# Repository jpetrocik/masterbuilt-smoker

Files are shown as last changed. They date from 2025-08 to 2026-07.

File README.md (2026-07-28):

# Smart Smoker Controller System

This project replaces the standard control board in an electric smoker, adding Wi-Fi, PID heat control, four built-in meat probes, a companion mobile app, and more. I can remotely monitor and control the cook from anywhere without being tied down to the smoker. The custom PID algorithm maintains an almost perfect internal temperature with minimal fluctuations. A variety of push notifications eliminate the need to constantly check on the cook throughout the day and night.

The primary goal of this project is to give me my weekend back. I don't want to constantly babysit the smoker when I rather be spending the day snowboarding, hitting trails, off-roading, or just hanging out with friends. The controller continuously monitors the smoker and meat temperature, sending real-time notifications to my phone when probes hit their target temperatures.

This specific board was designed as a drop-in replacement for Masterbuilt refrigerator-style smokers, but the system can be adapted to work with almost any electric smoker.

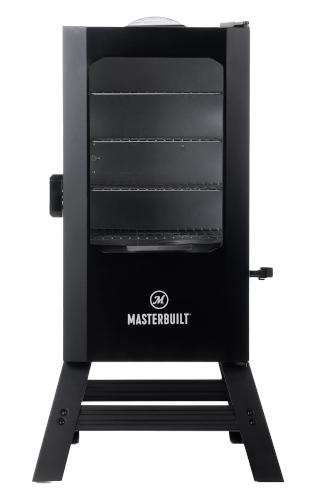
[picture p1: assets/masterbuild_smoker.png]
Masterbuilt Smoker


## Overview

This repository is split into four major components, each with its own detailed `README.md` file:

### 1. Mobile App (./www/README.md)
A Progressive Web App (PWA) that can be installed on your phone to run exactly like a native app, complete with real-time push notifications.

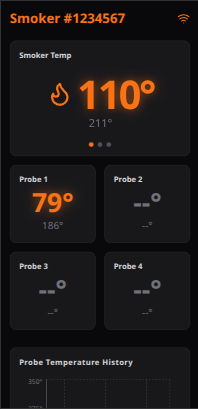
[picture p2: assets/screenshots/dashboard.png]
Dashboard Screenshot


### 2. Backend (./server/README.md)
The central nervous system of the project. It acts as the bridge between the physical smoker and the mobile application. The backend handles the complex algorithms for stall detection and logs high-resolution temperature history. The system is highly fault-tolerant: if the backend drops offline, the firmware will continue executing the active cook locally. If the backend loses connection to the smoker, an alert is sent immediately to your phone.

### 3. Firmware (./firmware/README.md)
The embedded code running on the physical microcontroller (ESP32) that directly interfaces with the smoker's hardware.

### 4. Hardware & PCBs (./hardware/README.md)
This directory contains the custom board designs. Currently, there are two boards designed to support Masterbuilt smokers: the main controller PCB and the power module. The custom power module replaces the stock mechanical relay with a Solid State Relay (SSR) to easily tolerate the rapid on/off switching required by the PID heat control.

## 📂 Repository Structure

```text
├── /server             # Node.js backend
├── /firmware           # Microcontroller code (ESP32/Arduino)
├── /www                # React / Vite / Tailwind PWA
├── /hardware           # Schematics and Gerber files
└── README.md           # Project overview (You are here)

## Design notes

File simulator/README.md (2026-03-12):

# Smoker Simulator

A Node.js-based MQTT simulator for testing the smoker backend and frontend.

## Features

- Simulates smoker temperature and probe temperatures using a realistic random walk algorithm
- Implements MQTT presence with Birth and Last Will and Testament (LWT) messages
- Publishes telemetry data to `smoker/<smokerId>/status` every 5 seconds
- Subscribes to and handles commands on `smoker/<smokerId>/command`
- Configurable number of active probes (0-4)

## Installation

1. Install dependencies:
```bash
npm install
```

## Configuration

Edit `config.json` to customize the simulator:

```json
{
  "smokerId": "smoker123",
  "mqttBroker": "mqtt://localhost:1883",
  "publishInterval": 5000,
  "activeProbes": 4
}
```

- **smokerId**: Unique identifier for the smoker
- **mqttBroker**: MQTT broker URL
- **publishInterval**: Telemetry publish interval in milliseconds
- **activeProbes**: Number of probes (0-4) that are "plugged in"

## Running the Simulator

```bash
npm start
```

The simulator will:
1. Connect to the MQTT broker
2. Publish an "online" birth message to `smoker/<smokerId>/presence`
3. Subscribe to `smoker/<smokerId>/command`
4. Publish telemetry data every 5 seconds to `smoker/<smokerId>/status`

## Telemetry Payload Structure

The simulator publishes JSON payloads matching the firmware structure:

```json
{
  "temperature": 224.5,
  "targetTemperature": 225.0,
  "cookTimer": 240,
  "cookTime": 300,
  "dutyCycle": 0.75,
  "probe1": 145.2,
  "targetProbe1": 165,
  "alarmProbe1": false,
  "probe2": 151.3,
  "targetProbe2": 160,
  "alarmProbe2": false
}
```

## Supported Commands

The simulator listens for and handles the following commands on `smoker/<smokerId>/command`:

- `setCookTime=<minutes>` - Set cook timer countdown
- `setProbeXTarget=<temp>` - Set probe X target temperature (X=1-4)
- `setProbeXLabel=<label>` - Set probe X label (logged but not stored)

## Random Walk Algorithm

Temperatures don't jump randomly but follow a realistic trend:
- Start at 75°F
- Each interval, add a random value between -1.0 and +2.0
- Cap maximum temperature at 225°F
- This creates a natural heating trend for frontend chart testing

## MQTT Topics

| Topic | Direction | Description |
|---|---|---|
| `smoker/<smokerId>/presence` | Publish | LWT/Birth messages ("online"/"offline") |
| `smoker/<smokerId>/status` | Publish | Telemetry data (JSON) |
| `smoker/<smokerId>/command` | Subscribe | Commands from backend/frontend |

## Testing with Backend

1. Start your backend server
2. Start the simulator: `npm start`
3. The backend should detect the smoker as "online" via the presence topic
4. Telemetry data will be published every 5 seconds

## Testing with Frontend

1. Start the backend server
2. Start the simulator
3. Start the frontend (from the `www` directory)
4. The frontend should display real-time smoker and probe data

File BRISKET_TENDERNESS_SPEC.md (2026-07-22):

# Brisket "Percent Done" / Tenderness Calculation Service

## Overview

Brisket tenderness is achieved through rendering collagen into gelatin. This rendering process is non-linear and accelerates exponentially at higher internal temperatures. This service calculates cumulative collagen rendering as a percentage (0-100%+) based on historical probe1 temperature telemetry from the smoker.

## Context

- Brisket cooks can run 12-18+ hours
- The smoker records probe telemetry every ~5 seconds, yielding massive datasets
- A direct calculation on raw 5-second data is expensive; aggregation to 1-minute intervals is more practical
- The calculation is slow enough that running it on every telemetry update (5-second intervals) is wasteful
- The metric is inherently slow-moving and doesn't require real-time precision

## Rendering Rate Model

The "Rendering Rate" (percentage of collagen rendered per hour) is determined by internal probe temperature, mapped via a lookup table. These rates represent the collagen-rendering speed at each temperature band.

| Temperature Range | Rate (% per hour) |
|---|---|
| < 140°F | 0% |
| 140–149°F | 1% |
| 150–159°F | 2% |
| 160–169°F | 3% |
| 170–179°F | 5% |
| 180–189°F | 9% |
| 190–194°F | 18% |
| 195–199°F | 25% |
| 200–204°F | 35% |
| 205–209°F | 55% |
| ≥ 210°F | 75% |

## Design Decisions

### 1. Where to Store the Calculated Value
- **Choice**: Include `percentRendered?: number` as an optional field in `SmokerTelemetryData`
- **Why**: The field is transient, computed, and specific to the WebSocket consumer. It doesn't belong in the persistent database record.
- **Implementation**: `insertTelemetry()` uses explicit column bindings, so adding the field to the interface has no DB side effects.

### 2. Calculation Frequency
- **Choice**: Run every 5 minutes via `setInterval`
- **Why**: Avoids expensive DB aggregation on every 5-second telemetry pulse. 5-minute staleness is acceptable for a slow-moving cook metric.
- **Alternative considered**: Lazy calculation with per-smoker 5-minute debounce (would add complexity; interval-based is simpler).

### 3. Active Smoker Tracking
- **Choice**: Track smokers via a `Set<string>` that gets populated on every telemetry event and cleared after each calculation tick
- **Why**: The scheduler doesn't need to query the database to find "active" smokers; they're implicitly the ones sending telemetry.
- **Scalability**: If there are many offline smokers, this avoids unnecessary calculations.

### 4. Cook Start Time
- **Choice**: Use `MIN(timestamp)` from `cook_history` for the smoker
- **Why**: Simple, authoritative, and doesn't require external tracking or configuration.
- **Limitation**: If history retention (`maxHistoryHours`) is shorter than the cook duration, the true cook start is lost. The calculation will be undercount. (Future enhancement: allow explicit cook start time tracking.)

### 5. Injection Point
- **Choice**: Attach `percentRendered` in `mqttService.ts:handleStatusMessage` before emitting to `telemetryEmitter`
- **Why**: Centralizes the enrichment logic at the source, and the WebSocket server receives already-augmented data.
- **Consideration**: The raw telemetry stored in `cook_history` never has `percentRendered` — it's a computed, transient field.

## Implementation

### Type Changes
**`server/src/types/index.ts`**
- Add `percentRendered?: number` to `SmokerTelemetryData` interface

### Database Functions
**`server/src/database/database.ts`**

Two new functions:

```typescript
export function getCookStartTime(smokerId: string): number | null
```
Returns the minimum timestamp from `cook_history` for the given `smokerId`, or `null` if no records exist.

```typescript
export function getMinuteAveragedProbeData(
  smokerId: string,
  startTime: number,
  endTime: number
): Array<{ minuteBucket: number; avgProbe1Temperature: number }>
```
Aggregates telemetry into 1-minute buckets and returns average probe1Temperature per bucket. Uses `timestamp / 60000` for bucketing (integer division in SQLite). Filters for `probe1Temperature IS NOT NULL`.

### Brisket Service
**`server/src/brisket/brisketService.ts`** (NEW file)

Exports:
- `startBrisketScheduler()` — initializes the 5-minute interval. Called once at server startup.
- `markSmokerActive(smokerId: string)` — records that a smoker has sent telemetry. Called on every MQTT status message.
- `getCachedPercentRendered(smokerId: string)` — returns the cached value (may be `undefined` if not yet computed). Called before emitting telemetry.

Internals:
- In-memory `Map<string, number>` for the cache (keyed by smokerId)
- In-memory `Set<string>` for active smokers
- `getRenderingRate(tempF: number): number` — switch/if-chain lookup
- `computeAndCache(smokerId: string)` — executes the full calculation pipeline

### MQTT Service Integration
**`server/src/mqtt/mqttService.ts`**

Two small changes:

1. In `connectMqtt()`, call `startBrisketScheduler()` alongside the existing `purgeOldHistory` interval.
2. In `handleStatusMessage()`, before emitting:
   - Call `markSmokerActive(smokerId)`
   - Retrieve `getCachedPercentRendered(smokerId)`
   - If defined, attach it to the outbound telemetry object before emitting

---

## Data Flow

```
Smoker sends MQTT status (every ~5 seconds)
  ↓
MQTT topic parsed → smokerId extracted
  ↓
handleStatusMessage(smokerId, payload)
  ├─ markSmokerActive(smokerId)
  ├─ insertTelemetry(timestampedData)                    [raw data, no percentRendered]
  ├─ percentRendered = getCachedPercentRendered(smokerId) [may be undefined]
  └─ telemetryEmitter.emit('telemetry', { ...data, percentRendered? })
       ↓
       WebSocket server broadcasts { type: 'live', data: enrichedTelemetry }
       ↓
       Frontend receives percentRendered (if defined)

Every 5 minutes (setInterval)
  ↓
brisketScheduler tick
  ├─ for each smokerId in activeSmokers:
  │   ├─ startTime = getCookStartTime(smokerId)
  │   ├─ buckets = getMinuteAveragedProbeData(smokerId, startTime, now)
  │   ├─ total = Σ(getRenderingRate(bucket.temp) / 60)
  │   └─ cache.set(smokerId, round(total, 2 decimals))
  └─ activeSmokers.clear()
```

---

## Edge Cases & Mitigations

### 1. First 5 Minutes of Uptime
- **Case**: Server starts but scheduler hasn't fired yet; telemetry arrives with `percentRendered: undefined`
- **Mitigation**: Frontend should handle missing field gracefully (display "—" or omit from UI)
- **Is this acceptable?** Yes for this project. If strict: could pre-compute for all smokers on startup.

### 2. Probe Unplugged / No Temperature Data
- **Case**: All `probe1Temperature` values are NULL for a smoker
- **Database query**: `getMinuteAveragedProbeData` returns empty array
- **Result**: `percentRendered` caches as `0.00`
- **Is this acceptable?** Yes. A missing probe means no rendering data available; zero is sensible.

### 3. Cook Longer Than History Retention Window
- **Case**: Cook runs 18 hours, but `maxHistoryHours` is 12
- **Impact**: `getCookStartTime` returns the oldest retained record, not the true cook start
- **Result**: Rendering percentage is underestimated
- **Mitigation**: Document the limitation. Future enhancement: track explicit cook start time in a separate table or in-memory map.

### 4. Multiple Concurrent Calculations for Same Smoker
- **Case**: If manual refresh or ad-hoc endpoint also triggers calculation
- **Impact**: Race condition on cache write (minor; last-write wins)
- **Mitigation**: Current design is simple and acceptable for single-server deployment. For HA, consider a lock or atomic update.

### 5. Stale Cache Across Server Restarts
- **Case**: Server restarts; cache is in-memory and lost
- **Impact**: First telemetry after restart has `percentRendered: undefined` until next 5-min tick
- **Mitigation**: On startup, could populate cache by running calculation for all smokers in DB. Not done currently to keep startup fast.

### 6. Smoker Inactive for > 5 Minutes
- **Case**: Telemetry stops arriving; `activeSmokers` set becomes empty
- **Impact**: Calculation no longer runs; cached value freezes at last update
- **Is this acceptable?** Yes. A frozen value for an inactive cook is correct. When telemetry resumes, the next tick will update it.

---

## Performance Considerations

- **Database query**: Compound index on `(smokerId, timestamp)` ensures the aggregation query is efficient even over 18 hours of data (≈65k 5-sec records = 1080 1-min buckets per cook).
- **Calculation cost**: One aggregation query + 1080 loop iterations (max) every 5 minutes. Negligible on a single-smoker or low-smoker workload.
- **Memory**: Cache is `Map<string, number>` (~64 bytes per smoker per entry). For 100 smokers, ~6.4 KB. Negligible.

---

## Testing / Verification

### Unit / Integration Test Ideas
1. Mock a sequence of temperature readings in different rate bands, verify the aggregation and sum.
2. Test `getRenderingRate()` edge cases (139.9°F, 140.0°F, 209.9°F, 210.0°F).
3. Test empty probe data returns 0%.

### Manual Verification
1. Start server + simulator; let it run 5+ minutes.
2. Open WebSocket connection; observe incoming `live` messages.
3. After first scheduler tick, `percentRendered` should appear in the data.
4. Manually run the aggregation SQL on the SQLite DB; compute a few buckets by hand.
5. Verify the cached value matches the manual calculation.

### Acceptance Criteria
- [ ] `percentRendered` appears in WebSocket `live` messages after first 5-min tick
- [ ] Value is a float rounded to 2 decimal places
- [ ] Value increases monotonically (or stays flat if probe temp doesn't rise)
- [ ] Value matches manual calculation from database

---

## Future Enhancements

1. **Explicit Cook Start Tracking**: Store cook start time in a separate table or in `smokers` table. Allow frontend to reset the clock mid-cook.
2. **Different Probes**: Generalize from `probe1` to any probe (most cooks use probe1, but some may use probe2 for brisket).
3. **Pre-Computed History**: Store daily snapshots of `percentRendered` for completed cooks (analytics / archive).
4. **Confidence Intervals**: If gaps exist in telemetry, note that the calculation is based on partial data.
5. **Temperature-Specific Alerts**: "Rendering accelerating — collagen breakdown in progress" at 190°F+.
6. **Target Rendering Level**: Allow user to set a target (e.g., 85%) and alert when reached, rather than just displaying a number.

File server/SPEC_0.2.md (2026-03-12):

## 1. Iteration 2: Hardware Control & Command Forwarding

### 1.1 Objective
Enable two-way communication by allowing connected WebSocket clients to send configuration and control commands down to the physical smoker hardware. The Node.js backend will act as a validating bridge, translating JSON WebSocket messages into plain-text MQTT payloads.

### 1.2 MQTT Command Contract
The backend will publish commands to a dedicated topic for each tenant.
* **Command Topic:** `smoker/<smoker_id>/command`
* **Payload Format:** Plain text string in `key=value` format (or just `key` for flag commands).
* **QoS:** `1` (At least once delivery ensures commands are not lost).
* **Retain:** `false` (Commands are instantaneous actions, not persistent states).

### 1.3 WebSocket Client-to-Server Protocol
Clients with an active WebSocket connection to `/smoker/<smoker_id>/data` can push messages to the server. The server must listen for incoming `message` events on the socket.
* **Expected Client Payload:** JSON object containing the command key and an optional value.
  ```json
  {
    "action": "command",
    "commandKey": "setTemp",
    "commandValue": 225
  }```

### 1.4 Protocol
* setTemp=[temp]
Set the target temperature (°F or °C, depending on configuration smoker configuration), e.g. setTemp=225

* setKp=[number]
Set the PID Kp value.
Example: setKp=300

* setKi=[number]
Set the PID Ki value.
Example: setKi=0.08

* setKd=[number]
Set the PID Kd value.
Example: setKd=0.5

* setCookTime=[minutes]
Set the cook timer duration in minutes.
Example: setCookTime=120

* setProbe[X]Label=[string] Set label for probe, where X is a number between 1-4, e.g. setProbe1Label=Brisket.

* setProbe[X]Target=[temp]
 Set target for probe, where X is a number between 1-4, e.g. setProbe1Target=120.

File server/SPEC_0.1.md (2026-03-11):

# Product Requirements Document & Technical Specification
**Project:** Multitenant Smoker Telemetry API

## 1. Product Vision & Objective
Create a headless Node.js middleware service that acts as the source of truth for physical meat smoker hardware. The objective is to ingest high-frequency MQTT telemetry from multitenant smoker devices, persist that data locally via SQLite, and expose that data to client applications (web or mobile) through a clean WebSocket and REST interface. The client application relies on this backend to handle all hardware discovery, data retention, and offline-state management.

## 2. Client Application "User" Stories
*(Note to Developer/AI: In these stories, the "User" is the front-end client application).*
* **Discovery:** As a client app, I need to query a REST endpoint to get a list of all currently registered smokers and their online/offline status, so I can render a dashboard menu for the human user. The endpoint should support filtering by status (all, online, offline) with a default of online.
* **State Syncing:** As a client app, when I open a WebSocket connection for a specific `smokerId`, I need to optionally request the last *X* seconds of historical data, so I can immediately draw a complete temperature chart without waiting for new data to trickle in.
* **Real-time Streaming:** As a client app, once connected via WebSocket, I need to receive pushed JSON payloads every time the hardware publishes a new temperature reading, so I can update the live UI gauges instantly.
* **Presence Alerting:** As a client app, I need the backend to push a specific WebSocket event if the hardware drops offline (triggered by the MQTT LWT), so I can immediately alert the human user that the cook is unmonitored.

## 3. Out of Scope (V1.0)
* **No UI/Frontend Generation:** Do not generate any HTML, CSS, React, or frontend client code. This is strictly a headless backend service.
* **No User Authentication:** The API and WebSockets do not require JWTs, API keys, or login systems. Assume a trusted local network environment.
* **No Hardware Control (Yet):** This version is read-only for telemetry. The client application cannot send target temperatures back to the hardware. 
* **No Cloud Syncing:** All data remains strictly on the local SQLite database.

---

## 4. Technical Implementation Specification

### 4.1 Overview
Create a backend server to manage telemetry data from multiple meat smokers. The service will ingest real-time telemetry data formatted as JSON via MQTT topics, maintain a configurable history window of that data in a local database, and publish both historical and real-time data to connected web clients via WebSockets.

### 4.2 Core Tech Stack
* **Language:** TypeScript (Strict mode enabled)
* **Runtime:** Node.js (Version 22.5+ required for native SQLite support)
* **Framework:** Express.js (for basic HTTP routing/setup)
* **Real-time Communication:** `ws` (Standard WebSockets) to allow strict path-based connections for frontend clients.
* **Hardware Ingestion:** `mqtt` (MQTT.js) to subscribe to presence and telemetry topics.
* **Database:** `node:sqlite` (Use Node's native SQLite implementation) to store historical telemetry data.
* **Configuration:** The app must read from a local `config.json` file on startup.
* **Documentation:** Swagger UI for REST API documentation (development only).

### 4.2.1 Swagger Documentation
* **Purpose:** Provide interactive API documentation for REST endpoints during development.
* **Access:** Available at `/api-docs` when `NODE_ENV=development`.
* **Generation:** Uses `swagger-jsdoc` to generate OpenAPI spec from JSDoc comments in route handlers.
* **Security:** Strictly disabled in production (checked via `process.env.NODE_ENV`).
* **Dependencies:** `swagger-ui-express`, `swagger-jsdoc`.

### 4.3 Multitenant Architecture & Lifecycle
This is a multitenant system where each physical smoker is a separate tenant identified by a unique `smokerId`. The backend identifies and registers tenants dynamically based on MQTT presence topics.
* **Registration:** When a new topic is published with a new `smokerId`, the backend registers the smoker.
* **TTL / Purge:** If a smoker's status remains "offline" for a configurable number of hours (defined in `config.json`), the backend must completely purge that smoker's historical data from the database and deregister the tenant.

**MQTT Contract for Discovery:**
* **Presence Topic:** `smoker/<smoker_id>/presence`
* **LWT (Death / Disconnect):** Configured by hardware on connection. Payload: `"offline"`, Retain: `true`, QoS: `1`.
* **Birth Message:** Published immediately by hardware upon successful connection. Payload: `"online"`, Retain: `true`, QoS: `1`.

### 4.4 Telemetry Data Ingestion
Data is published by the hardware every 30 seconds to a status topic.
* **Telemetry Topic:** `smoker/<smoker_id>/status`
* **JSON Payload Example:**
  ```json
  {
    "temperature": 224,
    "targetTemperature": 225,
    "cookTimer": 5014,
    "probe1": 98,
    "targetProbe1": 134,
    "probe2": 96,
    "targetProbe2": 134,
    "probe3": 98,
    "targetProbe3": 134,
    "probe4": 101,
    "targetProbe4": 134
  }```

### 4.5 Data Persistence (node:sqlite) 
The backend must maintain a rolling window of telemetry history in SQLite. The maximum retention time is determined by a "configurable hours of history" setting in config.json.
* Dynamic Probes: The fields probe1 through probe4 and their respective target fields are optional. They only appear in the MQTT payload when a physical probe is plugged into the hardware.
* Null Handling: The database schema must allow NULL values for these probe columns. If a probe is added mid-cook, start recording it. If removed, log it as NULL.
* Extensibility: The ingestion logic must ignore any unexpected JSON elements without throwing errors, allowing future firmware updates to add fields safely.

### 4.6 WebSocket Publishing & Retrieval
Clients connect to the backend via WebSockets to retrieve historical batches and stream real-time updates.
* Connection Path: ws://<host>/ws/smoker/<smoker_id>/data
* Historical Batching (Query Parameter): An optional since query parameter (representing seconds into the past) can be appended: /ws/smoker/12345/data?since=360.
  * If since is provided, the backend must immediately query SQLite for all records for that smoker_id created between now and since seconds ago, and send this batch to the client over the socket.
  * The since value cannot exceed the configured maximum history hours.
  * If no since parameter is provided, no historical batch is sent.
* Continuous Streaming: Once the connection is established (and any requested historical batch is sent), the backend must push all new incoming MQTT telemetry payloads for that specific smoker_id directly to the connected WebSocket client until the client disconnects.

### 5. Success Metrics & Acceptance Criteria
* The system successfully registers a new smokerId automatically upon receiving an MQTT Birth message.

* The system gracefully catches the MQTT LWT message and updates the database state to "offline".

* Connecting to ws://<host>/ws/smoker/<smoker_id>/data?since=3600 successfully pulls the last hour of data from SQLite and transmits it over the socket before streaming live updates.

* The backend runs cleanly via npm start with no TypeScript errors, reading all variables from config.json.

* The /api/smokers endpoint supports an optional "status" query parameter (all, online, offline) with a default of online, filtering the returned list accordingly.

### 6. Configuration File (config.json) 
The application must read its configuration from a config.json file at the root of the project. The AI should generate a default file using the exact structure below. All database retention, server ports, and MQTT connection logic must utilize these values dynamically.
```json
{
  "mqtt": {
    "host": "192.168.1.100",
    "port": 1883,
    "protocol": "mqtt",
    "username": "your_mqtt_user",
    "password": "your_mqtt_password",
    "clientIdPrefix": "smoker-backend-"
  },
  "server": {
    "port": 3000
  },
  "database": {
    "path": "./data/smoker_history.db",
    "maxHistoryHours": 6,
    "offlinePurgeHours": 1
  }
```

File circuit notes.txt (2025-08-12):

Circuit Notes

See the ADS1115 breakout board circuit for use of ferrite beads on VCC and GND.

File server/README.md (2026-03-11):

# Server

A TypeScript Node.js API Server.

## Getting Started

1. Install dependencies:
   ```bash
   npm install
   ```

2. Create a `.env` file based on `.env.example`:
   ```bash
   cp .env.example .env
   ```

3. Run the development server:
   ```bash
   npm run dev
   ```

4. Build for production:
   ```bash
   npm run build
   npm start
   ```

## Project Structure

```
├── src/
│   ├── controllers/
│   ├── middleware/
│   ├── models/
│   ├── routes/
│   ├── types/
│   └── index.ts
├── tests/
├── .env.example
├── package.json
└── tsconfig.json
```

## API Endpoints

- `GET /` - Welcome message
- `GET /health` - Health check
- `GET /api` - API base route

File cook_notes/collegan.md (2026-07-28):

# Following the Smoke Trails Collagen Rendering Formula

(https://smoketrailsbbq.com/brisket-holding-masterclass-and-tenderness-model/)

### Background

The smoker is a custom, ESP32-controlled electric smoker. The smoker's temperature is PID-controlled. Data from four brisket probes and the smoker's internal temperature sensor are published every five seconds to an MQTT topic. Software on a local server monitors this temperature data to calculate the percentage of collagen rendered.

### Cook Notes

1. The smoker was initially set to 250°F.
2. The initial brisket temperature was 49°F.
3. The brisket was wrapped when it reached 172°F.
4. When the brisket hit 195°F, the smoker temperature was reduced to 150°F.
5. At 195°F, the collagen was 72.7% rendered.
6. The brisket's internal temperature continued to rise, peaking at 199°F.
7. The smoker took 23 minutes to drop to 150°F.
8. After two hours, the internal brisket temperature had only dropped by 10°F.

> **Note:** I removed the brisket from the smoker after holding it for only two hours because the cooldown was extremely slow. At this point, the collagen rendering had reached 127%.

### Log of Collagen Rendering

**Note:** I am missing the logs between 140°F and 156°F. I would like to blame the software, but it was operator error. I retroactively calculated the collagen rendering for the lost data from the published mqtt data at 1.67%.

    Jul 27 19:54:20 hermes smoker[860809]: [BrisketRecipe] smokerId=11100 phase=cooking temp=157°F rate=2.61%/hr collagen=0.66%
    Jul 27 20:09:22 hermes smoker[860809]: [BrisketRecipe] smokerId=11100 phase=cooking temp=159°F rate=2.95%/hr collagen=1.39%
    Jul 27 20:24:24 hermes smoker[860809]: [BrisketRecipe] smokerId=11100 phase=cooking temp=160°F rate=3.14%/hr collagen=2.18%
    Jul 27 20:39:26 hermes smoker[860809]: [BrisketRecipe] smokerId=11100 phase=cooking temp=161°F rate=3.33%/hr collagen=3.02%
    Jul 27 20:54:27 hermes smoker[860809]: [BrisketRecipe] smokerId=11100 phase=cooking temp=162°F rate=3.54%/hr collagen=3.90%
    Jul 27 21:09:29 hermes smoker[860809]: [BrisketRecipe] smokerId=11100 phase=cooking temp=163°F rate=3.76%/hr collagen=4.85%
    Jul 27 21:24:31 hermes smoker[860809]: [BrisketRecipe] smokerId=11100 phase=cooking temp=168°F rate=5.10%/hr collagen=6.12%
    Jul 27 21:39:33 hermes smoker[860809]: [BrisketRecipe] smokerId=11100 phase=cooking temp=167°F rate=4.80%/hr collagen=7.33%
    Jul 27 21:54:35 hermes smoker[860809]: [BrisketRecipe] smokerId=11100 phase=cooking temp=168°F rate=5.10%/hr collagen=8.60%
    Jul 27 22:09:36 hermes smoker[860809]: [BrisketRecipe] smokerId=11100 phase=cooking temp=169°F rate=5.42%/hr collagen=9.96%
    Jul 27 22:24:38 hermes smoker[860809]: [BrisketRecipe] smokerId=11100 phase=cooking temp=170°F rate=5.76%/hr collagen=11.40%
    Jul 27 22:39:40 hermes smoker[860809]: [BrisketRecipe] smokerId=11100 phase=cooking temp=172°F rate=6.50%/hr collagen=13.03%
    Jul 27 22:54:42 hermes smoker[860809]: [BrisketRecipe] smokerId=11100 phase=cooking temp=173°F rate=6.91%/hr collagen=14.76%
    Jul 27 23:09:44 hermes smoker[860809]: [BrisketRecipe] smokerId=11100 phase=cooking temp=174°F rate=7.35%/hr collagen=16.60%
    Jul 27 23:24:45 hermes smoker[860809]: [BrisketRecipe] smokerId=11100 phase=cooking temp=175°F rate=7.81%/hr collagen=18.56%
    Jul 27 23:39:47 hermes smoker[860809]: [BrisketRecipe] smokerId=11100 phase=cooking temp=176°F rate=8.29%/hr collagen=20.64%
    Jul 27 23:54:49 hermes smoker[860809]: [BrisketRecipe] smokerId=11100 phase=cooking temp=177°F rate=8.81%/hr collagen=22.85%
    Jul 28 00:09:51 hermes smoker[860809]: [BrisketRecipe] smokerId=11100 phase=cooking temp=178°F rate=9.37%/hr collagen=25.19%
    Jul 28 00:24:53 hermes smoker[860809]: [BrisketRecipe] smokerId=11100 phase=cooking temp=179°F rate=9.95%/hr collagen=27.69%
    Jul 28 00:39:54 hermes smoker[860809]: [BrisketRecipe] smokerId=11100 phase=cooking temp=180°F rate=10.58%/hr collagen=30.34%
    Jul 28 00:54:56 hermes smoker[860809]: [BrisketRecipe] smokerId=11100 phase=cooking temp=181°F rate=11.24%/hr collagen=33.15%
    Jul 28 01:09:58 hermes smoker[860809]: [BrisketRecipe] smokerId=11100 phase=cooking temp=182°F rate=11.95%/hr collagen=36.14%
    Jul 28 01:25:00 hermes smoker[860809]: [BrisketRecipe] smokerId=11100 phase=cooking temp=182°F rate=11.95%/hr collagen=39.14%
    Jul 28 01:40:02 hermes smoker[860809]: [BrisketRecipe] smokerId=11100 phase=cooking temp=184°F rate=13.49%/hr collagen=42.51%
    Jul 28 01:55:03 hermes smoker[860809]: [BrisketRecipe] smokerId=11100 phase=cooking temp=185°F rate=14.34%/hr collagen=46.11%
    Jul 28 02:10:05 hermes smoker[860809]: [BrisketRecipe] smokerId=11100 phase=cooking temp=187°F rate=16.19%/hr collagen=50.16%
    Jul 28 02:25:07 hermes smoker[860809]: [BrisketRecipe] smokerId=11100 phase=cooking temp=189°F rate=18.28%/hr collagen=54.74%
    Jul 28 02:40:09 hermes smoker[860809]: [BrisketRecipe] smokerId=11100 phase=cooking temp=191°F rate=20.64%/hr collagen=59.91%
    Jul 28 02:55:11 hermes smoker[860809]: [BrisketRecipe] smokerId=11100 phase=cooking temp=194°F rate=24.77%/hr collagen=66.12%
    Jul 28 03:10:12 hermes smoker[860809]: [BrisketRecipe] smokerId=11100 phase=cooking temp=195°F rate=26.33%/hr collagen=72.71%
    Jul 28 03:10:12 hermes smoker[860809]: [BrisketRecipe] smokerId=11100 resting phase started (collagen=72.71%, temp=195°F) — lowering temp to 150°F
    Jul 28 03:25:14 hermes smoker[860809]: [BrisketRecipe] smokerId=11100 phase=resting temp=197°F rate=29.73%/hr collagen=80.16%
    Jul 28 03:40:16 hermes smoker[860809]: [BrisketRecipe] smokerId=11100 phase=resting temp=199°F rate=33.57%/hr collagen=88.57%
    Jul 28 03:55:18 hermes smoker[860809]: [BrisketRecipe] smokerId=11100 phase=resting temp=199°F rate=33.57%/hr collagen=96.98%
    Jul 28 04:10:20 hermes smoker[860809]: [BrisketRecipe] smokerId=11100 phase=resting temp=197°F rate=29.73%/hr collagen=104.43%
    Jul 28 04:10:20 hermes smoker[860809]: [BrisketRecipe] smokerId=11100 brisket finished (collagen=104.43%, temp=197°F) — cook complete
    Jul 28 04:25:21 hermes smoker[860809]: [BrisketRecipe] smokerId=11100 phase=finished temp=196°F rate=27.98%/hr collagen=111.44%
    Jul 28 04:40:23 hermes smoker[860809]: [BrisketRecipe] smokerId=11100 phase=finished temp=193°F rate=23.31%/hr collagen=117.28%
    Jul 28 04:55:25 hermes smoker[860809]: [BrisketRecipe] smokerId=11100 phase=finished temp=191°F rate=20.64%/hr collagen=122.45%
    Jul 28 05:10:27 hermes smoker[860809]: [BrisketRecipe] smokerId=11100 phase=finished temp=190°F rate=19.43%/hr collagen=127.32%

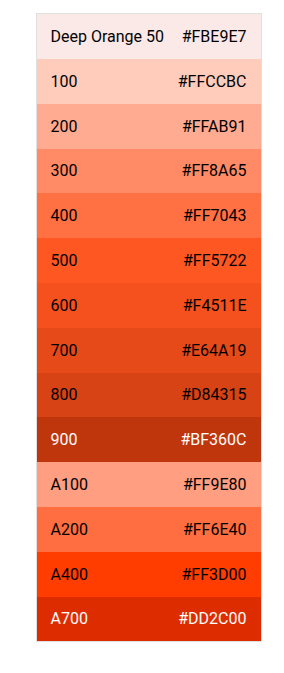
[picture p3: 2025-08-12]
notes/Screenshot_20250811_233012.png

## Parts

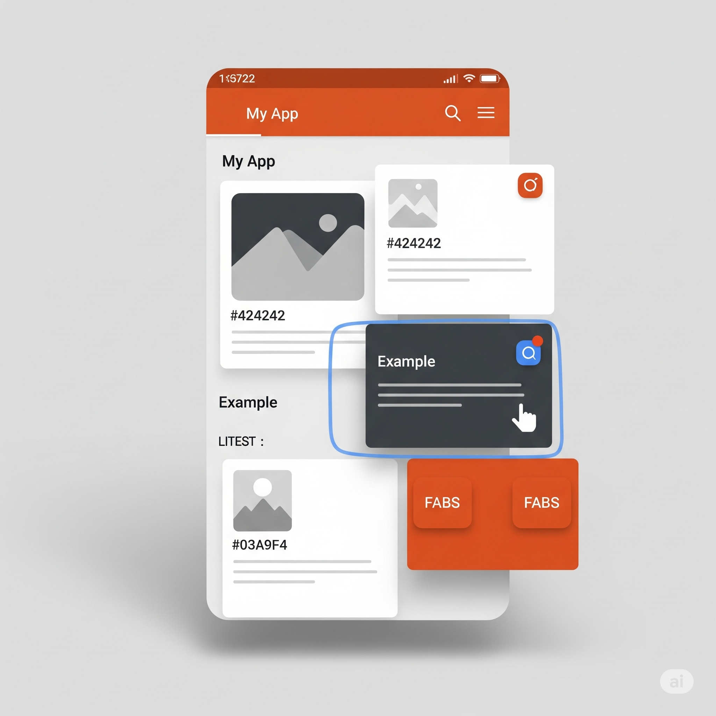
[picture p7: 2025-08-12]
notes/deep_order_theme_mockup.png

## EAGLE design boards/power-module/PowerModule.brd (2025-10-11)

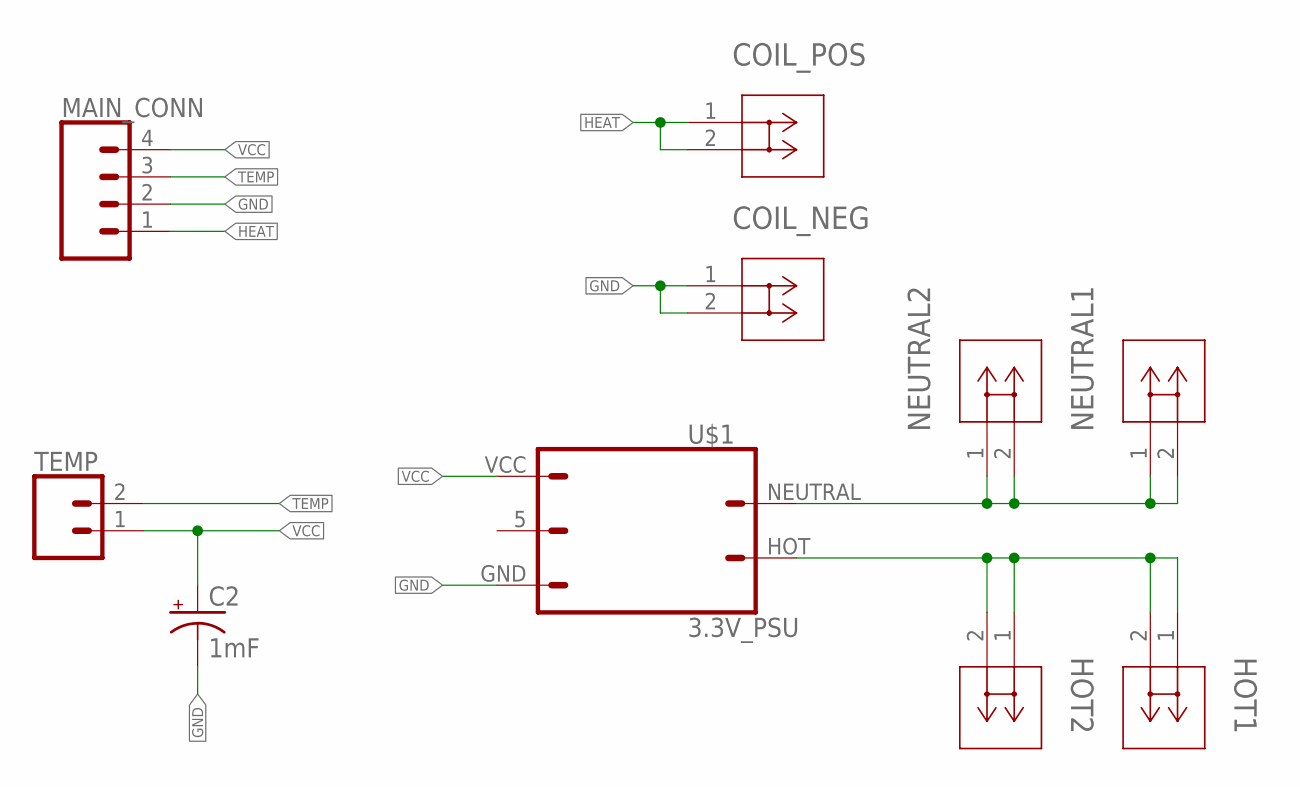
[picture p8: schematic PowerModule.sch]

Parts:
C2: 1mF; CPOL-RADIAL-5MM-10MM
COIL_NEG: 1287; CONN_1287_KEY
COIL_POS: 1287; CONN_1287_KEY
HOT1, HOT2: 1287; CONN_1287_KEY
MAIN_CONN: CONN_04PTH; 1X04
NEUTRAL1, NEUTRAL2: 1287; CONN_1287_KEY
TEMP: CONN_02; 1X02
U$1: 3.3V_PSU; 1X03

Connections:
GND: C2.-, COIL_NEG.1, COIL_NEG.2, MAIN_CONN.2, U$1.GND
HEAT: COIL_POS.1, COIL_POS.2, MAIN_CONN.1
HOT: HOT1.1, HOT1.2, HOT2.1, HOT2.2, U$1.HOT
NEUTRAL: NEUTRAL1.1, NEUTRAL1.2, NEUTRAL2.1, NEUTRAL2.2, U$1.NEUTRAL
TEMP: MAIN_CONN.3, TEMP.2
VCC: C2.+, MAIN_CONN.4, TEMP.1, U$1.VCC

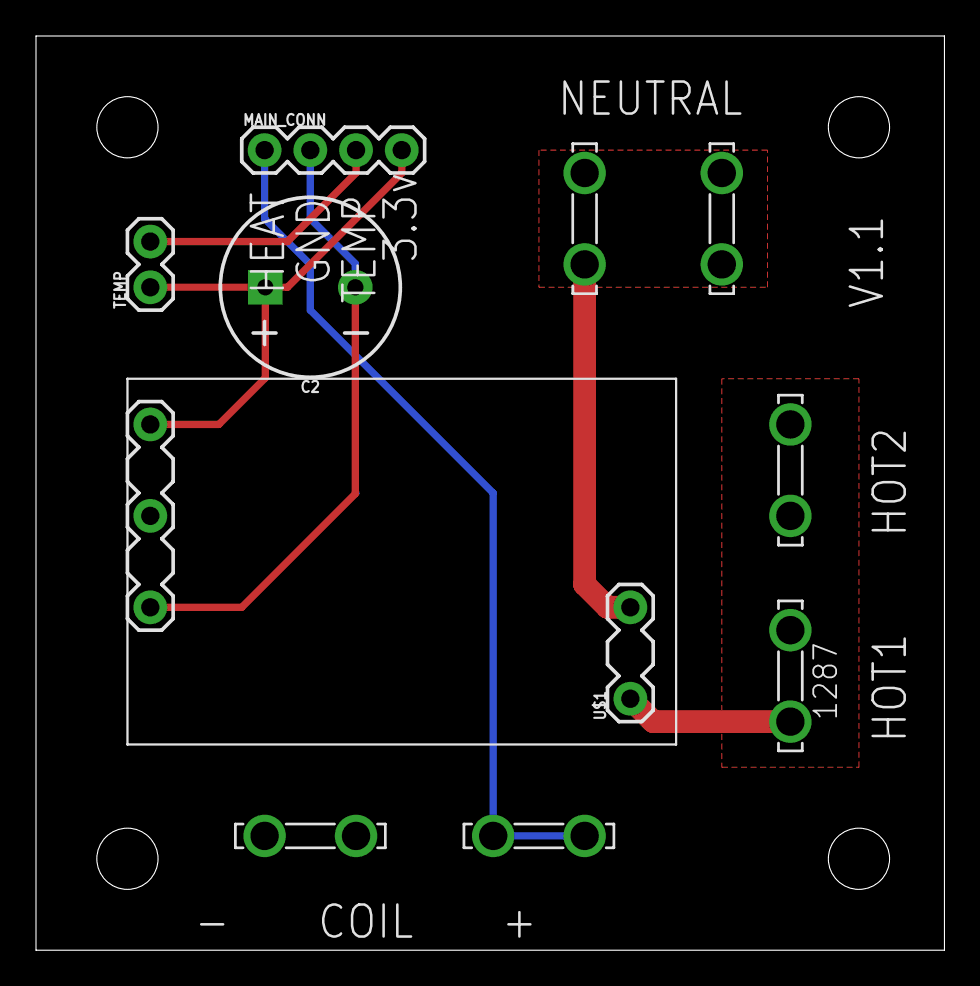
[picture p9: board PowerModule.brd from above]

Board: 2 copper layers, 50.5 x 50.8 mm, 10 parts (0 on the bottom side), 6 nets.

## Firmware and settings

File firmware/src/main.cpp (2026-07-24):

#include <Arduino.h>
#include <PID_v1.h>
#include <Adafruit_ADS1X15.h>
#include "config.h"
#include "server.h"
#include "interface.h"
#include "status.h"
#include "units.h"
#include "debug.h"

// Maintain Temp PID settings
// double Kp = 150, Ki = 0.08, Kd = 20;

double Kp = 200, Ki = 0.08, Kd = 10;

// adc buffers
uint16_t temp_buffer[ADC_SAMPLE_SIZE] = {0};
uint8_t temp_index = 0;
uint16_t probe1_buffer[ADC_SAMPLE_SIZE] = {0};
uint8_t probe1_index = 0;
uint16_t probe2_buffer[ADC_SAMPLE_SIZE] = {0};
uint8_t probe2_index = 0;
uint16_t probe3_buffer[ADC_SAMPLE_SIZE] = {0};
uint8_t probe3_index = 0;
uint16_t probe4_buffer[ADC_SAMPLE_SIZE] = {0};
uint8_t probe4_index = 0;

// main loop variables
unsigned long now;
bool abortError = false;
int16_t reading;
uint32_t voltage;
uint32_t resistance;
status_state currentSmokerState;
long lastProbeRead;

// PID variables
double timeOn;
unsigned long windowStartTime;
PID heatControlPid(&currentSmokerState.temperature, &timeOn, &currentSmokerState.targetTemperature, Kp, Ki, Kd, DIRECT);

Adafruit_ADS1115 ads1;
Adafruit_ADS1115 ads2;

char debugBuffer[100];
uint32_t resistance1;
uint32_t resistance2;
u_int32_t resistance3;

void computePID()
{
  heatControlPid.Compute();
  currentSmokerState.dutyCycle = timeOn / (double)PID_WINDOW_SIZE;

  // if (timeOn < 100)
  //   timeOn = 0;

  // recalcuate next PID window
  if (now - windowStartTime > PID_WINDOW_SIZE)
    windowStartTime += PID_WINDOW_SIZE;

  if (timeOn > now - windowStartTime)
  {
    digitalWrite(HEAT_PIN, HIGH);
    digitalWrite(LED_PIN, HIGH);
  }
  else
  {
    digitalWrite(HEAT_PIN, LOW);
    digitalWrite(LED_PIN, LOW);
  }
}

uint32_t readADC_Avg(uint16_t sample, uint16_t adc_buffer[], uint8_t *adc_index_ptr)
{
  int i = 0;
  uint32_t sum = 0;
  uint8_t adc_index = *adc_index_ptr;

  adc_buffer[adc_index++] = sample;
  if (adc_index == ADC_SAMPLE_SIZE)
  {
    adc_index = 0;
  }
  for (i = 0; i < ADC_SAMPLE_SIZE; i++)
  {
    sum += adc_buffer[i];
  }

  *adc_index_ptr = adc_index;

  return sum / ADC_SAMPLE_SIZE;
}

float calculate_Temperature_SH_Value(uint32_t res)
{
  float logRes = log(res); // Pre-Calcul for Log(R2)
  float temp = (1.0 / (TEMP_A + TEMP_B * logRes + TEMP_C * logRes * logRes * logRes));
  return temp - 273.15; // convert Kelvin to *C
}

float calculate_Probe_SH_Value(uint32_t res)
{
  float logRes = log(res); // Pre-Calcul for Log(R2)
  float temp = (1.0 / (PROBE_A + PROBE_B * logRes + PROBE_C * logRes * logRes * logRes));
  return temp - 273.15; // convert Kelvin to *C
}

float calculate_Temperature_B_Value(uint32_t res, float b)
{
  // B value calculation
  float bVale = res / 100000.0; // (R/Ro)
  bVale = log(bVale);           // ln(R/Ro)
  bVale /= b;                   // 1/B * ln(R/Ro)
  bVale += 1.0 / (25 + 273.15); // + (1/To)
  bVale = 1.0 / bVale;          // Invert
  bVale -= 273.15;

  return bVale;
}

double readTemperature(Adafruit_ADS1115 *ads, int input, uint16_t series_resistor, uint16_t adc_buffer[], uint8_t *adc_index_ptr)
{
  int adsDeviceNumber = ads == &ads1 ? ADS1 : ADS2;

  reading = ads->readADC_SingleEnded(input);

  voltage = reading * 125000ul / 1000000;

  // TODO Handle missing probe
  if (voltage == 0)
  {
    return 0.0; // avoid division by zero
  }

  voltage = readADC_Avg(voltage, adc_buffer, adc_index_ptr);

  // Voltage is 3.3V, extra zeros are for additional precision during int math
  resistance = (series_resistor * (33000000 / voltage - 10000)) / 10000;

  double temperature = 0;
  if (adsDeviceNumber == ADS1)
  {
#ifdef B_MODEL
    temperature = calculate_Temperature_B_Value(resistance, PROBE_BETA);
#else
    temperature = calculate_Probe_SH_Value(resistance);
#endif
  }
  else
  {
#ifdef B_MODEL
    temperature = calculate_Temperature_B_Value(resistance, TEMP_BETA);
#else
    temperature = calculate_Temperature_SH_Value(resistance);
#endif
  }

#ifdef DEBUG_PROBE
  debug_sendProbeDebug(adsDeviceNumber, input, resistance, voltage, temperature);
#endif

  return temperature;
}

void handleCommandEvent(char *data)
{

  Serial.print("Recieved: ");
  Serial.println(data);

  if (strncmp(data, "setTemp=", 8) == 0)
  {

    double newRequestedTargetTemp = units_fromLocalTemperature(atoi(&data[8]));
    if (newRequestedTargetTemp < MIN_TEMP || newRequestedTargetTemp > MAX_TEMP)
    {
      return;
    }

    /**
     * When setting the temp to 0, stop cook timer and cancel scheduled shutdown.
     * When setting to temp from 0 to non-zero, start timer
     * When setting the temp from non-zero to non-zero, do nothing
     */
    if (newRequestedTargetTemp == 0.0)
    {
      currentSmokerState.cookStartTime = 0;
      currentSmokerState.cookEndTime = 0;
    }
    else if (currentSmokerState.targetTemperature == 0.0)
    {
      currentSmokerState.cookStartTime = millis();
    }
    currentSmokerState.targetTemperature = newRequestedTargetTemp;
    heatControlPid.SetMode(AUTOMATIC);
  }
  else if (strncmp(data, "setKp=", 6) == 0)
  {
    Kp = atof(&data[6]);
#ifdef DEBUG_PROBE
    debug_sendPidSettings(Kp, Ki, Kd);
#endif
    heatControlPid.SetTunings(Kp, Ki, Kd);
  }
  else if (strncmp(data, "setKd=", 6) == 0)
  {
    Kd = atof(&data[6]);
#ifdef DEBUG_PROBE
    debug_sendPidSettings(Kp, Ki, Kd);
#endif
    heatControlPid.SetTunings(Kp, Ki, Kd);
  }
  else if (strncmp(data, "setKi=", 6) == 0)
  {
    Ki = atof(&data[6]);
#ifdef DEBUG_PROBE
    debug_sendPidSettings(Kp, Ki, Kd);
#endif
    heatControlPid.SetTunings(Kp, Ki, Kd);
  }
  else if (strncmp(data, "setCookTime=", 12) == 0)
  {
    currentSmokerState.cookEndTime = millis() + (atoi(&data[12]) * 60000l);
  }
  else if (strncmp(data, "setProbe1Target=", 16) == 0)
  {
    currentSmokerState.targetProbe1 = units_fromLocalTemperature(atoi(&data[16]));
  }
  else if (strncmp(data, "setProbe2Target=", 16) == 0)
  {
    currentSmokerState.targetProbe2 = units_fromLocalTemperature(atoi(&data[16]));
  }
  else if (strncmp(data, "setProbe3Target=", 16) == 0)
  {
    currentSmokerState.targetProbe3 = units_fromLocalTemperature(atoi(&data[16]));
  }
  else if (strncmp(data, "setProbe4Target=", 16) == 0)
  {
    currentSmokerState.targetProbe4 = units_fromLocalTemperature(atoi(&data[16]));
  }
#ifdef LCD_SUPPORTED
  else if (strncmp(data, "lcdUpdate", 9) == 0)
  {
    lcd_updateSmokerState();
  }
  else if (strncmp(data, "setProbe1Label=", 15) == 0)
  {
    lcd_setProbeLabel(PROBE1, &data[15]);
  }
  else if (strncmp(data, "setProbe2Label=", 15) == 0)
  {
    lcd_setProbeLabel(PROBE2, &data[15]);
  }
  else if (strncmp(data, "setProbe3Label=", 15) == 0)
  {
    lcd_setProbeLabel(PROBE3, &data[15]);
  }
  else if (strncmp(data, "setProbe4Label=", 15) == 0)
  {
    lcd_setProbeLabel(PROBE4, &data[15]);
  }
  else if (strncmp(data, "wifiConnected", 13) == 0)
  {
    lcd_wifiConnected();
  }
  else if (strncmp(data, "wifiDisconnected", 16) == 0)
  {
    lcd_wifiDisconnected();
  }
#endif // LCD_SUPPORTED
}

void setup(void)
{
  Serial.begin(115200);

  status_init();

  windowStartTime = millis();

  heatControlPid.SetOutputLimits(0, PID_WINDOW_SIZE);
  heatControlPid.SetMode(AUTOMATIC);

  ws_init(&currentSmokerState, handleCommandEvent);

  pinMode(HEAT_PIN, OUTPUT);
  digitalWrite(HEAT_PIN, LOW);
  pinMode(LED_PIN, OUTPUT);
  digitalWrite(LED_PIN, LOW);

  if (!ads1.begin())
  {
    Serial.println("Failed to initialize ADS1.");
    abortError = true;
  }
  else
  {
    ads1.setGain(GAIN_ONE); // Sets ADS1 range to +/- 4.096V
  }

  if (!ads2.begin(0x49))
  {
    Serial.println("Failed to initialize ADS2.");
    abortError = true;
  }
  else
  {
    ads2.setGain(GAIN_ONE); // Sets ADS2 range to +/- 4.096V
  }

#ifdef LCD_SUPPORTED
  lcd_init(&currentSmokerState);
#endif // LCD_SUPPORTED
}

void loop(void)
{
  now = millis();

#ifdef LCD_SUPPORTED
  lcd_loop(now);
#endif // LCD_SUPPORTED

  if (abortError)
  {
    digitalWrite(HEAT_PIN, LOW);
    digitalWrite(LED_PIN, LOW);

    return;
  }

  if (currentSmokerState.temperature > ABORT_TEMP)
  {
    Serial.println("Temperature too high, aborting!");
    abortError = true;
  }

  // Checks for cook time exceeded and reset target temperature
  if (currentSmokerState.cookEndTime > 0 && currentSmokerState.cookEndTime < now)
  {
    Serial.println("Cook time exceeded, turning off heating.");
    currentSmokerState.cookEndTime = 0;
    currentSmokerState.targetTemperature = 0;
    currentSmokerState.dutyCycle = 0;
    digitalWrite(HEAT_PIN, LOW);
    digitalWrite(LED_PIN, LOW);
    timeOn = 0;
  }

  // Reads probes every half second
  if (now - lastProbeRead > 500)
  {
    currentSmokerState.temperature = readTemperature(&ads2, 1, TEMP_SERIES_RESISTOR, temp_buffer, &temp_index);
    currentSmokerState.probe1 = readTemperature(&ads1, 0, PROBE_SERIES_RESISTOR, probe1_buffer, &probe1_index);
    currentSmokerState.probe2 = readTemperature(&ads1, 1, PROBE_SERIES_RESISTOR, probe2_buffer, &probe2_index);
    currentSmokerState.probe3 = readTemperature(&ads1, 2, PROBE_SERIES_RESISTOR, probe3_buffer, &probe3_index);
    currentSmokerState.probe4 = readTemperature(&ads1, 3, PROBE_SERIES_RESISTOR, probe4_buffer, &probe4_index);

    // Check alarm conditions
    currentSmokerState.alarmProbe1 = (currentSmokerState.targetProbe1 > 0 && currentSmokerState.probe1 > currentSmokerState.targetProbe1);
    currentSmokerState.alarmProbe2 = (currentSmokerState.targetProbe2 > 0 && currentSmokerState.probe2 > currentSmokerState.targetProbe2);
    currentSmokerState.alarmProbe3 = (currentSmokerState.targetProbe3 > 0 && currentSmokerState.probe3 > currentSmokerState.targetProbe3);
    currentSmokerState.alarmProbe4 = (currentSmokerState.targetProbe4 > 0 && currentSmokerState.probe4 > currentSmokerState.targetProbe4);

    lastProbeRead = now;
  }

  if (currentSmokerState.targetTemperature > MIN_TEMP)
  {
    computePID();
  }

  ws_loop(now);
}

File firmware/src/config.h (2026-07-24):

#ifndef CONFIG_H
#define CONFIG_H

#define WIFI_SSID "PNET"
#define WIFI_PASSWORD "5626278472"

//#define LCD_SUPPORTED  // Uncomment to enable LCD support
#define OTA_ENABLED

#define ADC_SAMPLE_SIZE 10

#define TEMP_SERIES_RESISTOR 22000
#define PROBE_SERIES_RESISTOR 10000

#define HEAT_PIN 5
#define LED_PIN 2 //TODO Consider adding LED to HEAT curcuit

//https://www.thinksrs.com/downloads/programs/therm%20calc/ntccalibrator/ntccalculator.html
//  81(27.2)          48407
//  174(78.9)         8456
//  286(141)          2094
#define TEMP_A -0.2613164095e-3
#define TEMP_B 3.670228955e-4
#define TEMP_C -2.935194202e-7
#define TEMP_BETA 3568.45

//https://www.thinksrs.com/downloads/programs/therm%20calc/ntccalibrator/ntccalculator.html
//  81(27.2)           112222
//  174(78.9)          14000
//  286(141)           2619
#define PROBE_A 0.1772729832e-3
#define PROBE_B 2.952734660e-4
#define PROBE_C -1.789284692e-7
#define PROBE_BETA 4256.98

#define MIN_TEMP 37.0
#define MAX_TEMP 135.0
#define ABORT_TEMP 175.0

// #define B_MODEL

#define PID_WINDOW_SIZE 2000

#define FERINHEIT // Uncomment to use Fahrenheit instead of Celsius

#define MQTT_ENABLED
#define MQTT_SERVER "mqtt.petrocik.net"
#define MQTT_CLIENT_ID_PREFIX "smoker"
#define MQTT_STATUS_TOPIC "smoker/%d/status"
#define MQTT_COMMAND_TOPIC "smoker/%d/command"
#define MQTT_DEBUG_TOPIC "smoker/%d/debug"
#define MQTT_PRESENCE_TOPIC "smoker/%d/presence"

#define ADS1 1
#define ADS2 2

//#define DEBUG_PROBE

#endif // CONFIG_H

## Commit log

2022-12-13 No working PID
2022-12-14 Working PID
2023-01-18 Added probe
2023-02-26 New PROBE_A/B/C
2023-03-09 Added eagle files
    [ControlModule.brd, ControlModule.sch, PowerModule.brd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]
2023-03-12 using adc functions and new thermistor a/b/c
2025-03-12 Add kicad files
    [PowerModule.kicad_pcb, PowerModule.kicad_sch]
2025-05-29 kicad files
    [ControlModule.kicad_pcb, ControlModule.kicad_sch]
2025-06-02 Switching to ADS1115
2025-06-03 Probes working with ADS1115
2025-08-02 board version 2.0
    [ControlModule.brd, ControlModule.kicad_pcb, ControlModule.kicad_sch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]
2025-08-12 Added deep orange theme samples
2025-08-25 Fixed devide by zero error
    [config.h, main.cpp, server.cpp]
2025-08-25 Updated probe ABC numbers
2025-09-08 Improved PID and ABC settings
2025-10-06 Added power modules board
    [PowerModule.brd, PowerModule.sch]
2025-10-07 update board with lcd
2025-10-11 Fixed issue with UI not compiling
    [config.h, main.cpp]
2026-03-12 Added presence LWT and removed device topic code
2026-03-12 Renames json properties from probe[X][Property] and prefixed smoker
2026-03-21 Fixed mixed up between probeTemp and probeTarget
2026-03-24 Improved temperature simulation
2026-03-24 Speed up probe telemetry growth
2026-03-24 Fixed issue with timer alter not sending if the timer is reset after the sending and alert the first time
2026-05-22 Fixed truncated status messages
    [config.h, mqtt.cpp]
2026-05-22 Fixed issue with temp increament and decreament button on trigger correctly
2026-07-22 Modified ADS gain, temp resistor, and PID settings
2026-07-23 Moved stall detection to stallDetectionService
2026-07-28 Reimplemented stall detection logic
2026-07-28 Changed to run stall detection every 5 minutes

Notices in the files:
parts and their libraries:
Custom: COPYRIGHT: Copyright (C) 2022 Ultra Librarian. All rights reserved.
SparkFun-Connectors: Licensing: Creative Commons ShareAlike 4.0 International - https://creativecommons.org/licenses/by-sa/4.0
